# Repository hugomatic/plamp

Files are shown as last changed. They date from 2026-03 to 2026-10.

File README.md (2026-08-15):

# Plamp

Local-first hydroponics automation for Raspberry Pi and MicroPython Picos. Picos run lights and pumps independently; the Pi adds configuration, monitoring, pictures, agents, and a fallback web UI.

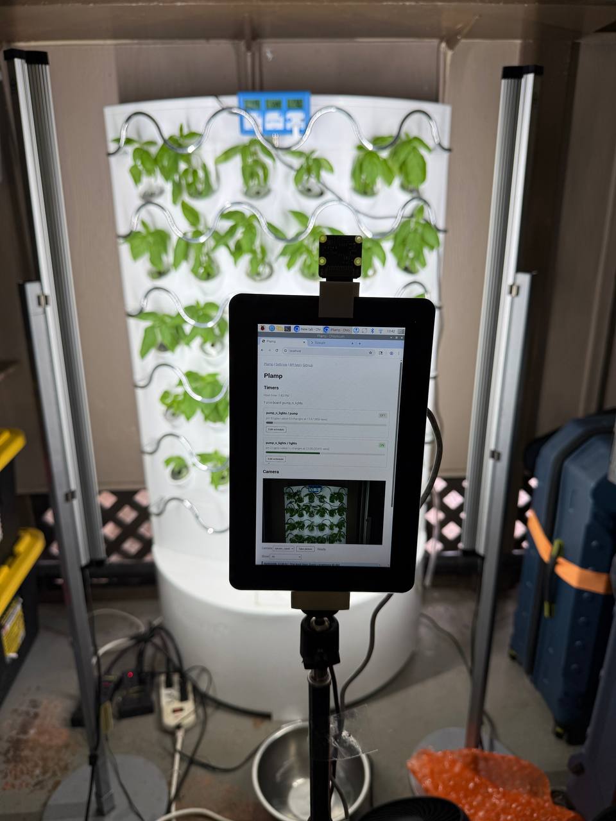
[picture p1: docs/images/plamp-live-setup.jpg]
Plamp running with basil tray, touchscreen UI, and camera


## Install

On a Raspberry Pi:

```bash
curl -fsSL https://raw.githubusercontent.com/hugomatic/plamp/main/deploy/bootstrap/install-plamp.sh | bash
```

This installs Plamp and starts `plamp-web` on `127.0.0.1:8000`. Useful options:

```bash
# Public port 80 through nginx
curl -fsSL https://raw.githubusercontent.com/hugomatic/plamp/main/deploy/bootstrap/install-plamp.sh | bash -s -- --public

# Update OS packages during installation
curl -fsSL https://raw.githubusercontent.com/hugomatic/plamp/main/deploy/bootstrap/install-plamp.sh | bash -s -- --update-os

# Install somewhere else
curl -fsSL https://raw.githubusercontent.com/hugomatic/plamp/main/deploy/bootstrap/install-plamp.sh | bash -s -- --plamp-dir ~/code/plamp
```

The installer labels required runtime dependencies separately from the tools
included for humans and agents. See [Host tools](./docs/host-tools.md).

Host lifecycle commands use `plampctl`:

```bash
systemctl is-active plamp-web
./plampctl restart
./plampctl upgrade
```

## Operate Plamp

Select this checkout, then use the `plamp` module's direct CLI:

```bash
source ./setup.sh
plamp context
plamp config get
plamp pico report pump_lights
plamp pico pulse pump_lights 21 5
plamp pico configure pump_lights compiled-state.json
plamp pico upgrade pump_lights compiled-state.json
plamp camera capture rpicam_cam0
```

Inspect the stable USB serial before onboarding a Plamp8 controller, and preview
the exact action before authorizing it:

```bash
plamp controllers candidates
plamp controllers add plamp8 --serial <serial> --profile plamp8
plamp controllers add plamp8 --serial <serial> --profile plamp8 --provision --apply
```

The middle command is a read-only preview: it reads the explicitly selected Pico
but changes neither firmware nor host files. Identityless, foreign, unsupported,
and PWM reports are rejected. Protocol 2 requires provisioning; protocol 3 can be
imported only when its generated revision and complete Plamp8 GPIO profile match
exactly. Add `--apply` without `--provision` to persist that observed validated
state. If the preview requires provisioning, the last command is the explicit
mutation that reflashes and resets the selected controller; confirm manual
switches and connected loads are safe first.

Use `-` instead of `compiled-state.json` to read the complete compiled scheduler state from stdin. Configure sends that state through the shared locked Pico protocol. Upgrade renders the current generic scheduler firmware, seeds both state slots, resets once, and verifies the reconnected report. These commands work while the service is running or stopped and do not contact `plamp-web`. Remote agents can use either the REST CLI or direct CLI over SSH.

During migration, the explicitly named REST compatibility client remains available as
`python3 -m plamp_cli`; it is not the command named `plamp`.

`setup.sh [DATA_DIR]` selects the checkout and instance for the current shell. It exports `PLAMP_ROOT` and `PLAMP_DATA_DIR`, and makes the checkout-owned `bin/plamp` launcher available without installing Plamp as a Python package. Without an argument, data defaults to `$PLAMP_ROOT/data`. Source another checkout's setup script to switch versions without leaving its executable paths behind.

See the direct CLI with `plamp --help`, or the
[REST compatibility reference](./plamp_cli/README.md).

## Generate printable CAD

The direct CLI generates the default product when one CAD system is available:

```bash
plamp cad generate
```

Discover the catalog or make a more specific selection when needed:

```bash
plamp cad systems
plamp cad models --system plamp
plamp cad sets plamp8 --system plamp
plamp cad products --system plamp
plamp cad generate --system plamp --product fuse-box
plamp cad runs plamp8
plamp cad show RUN_ID
```

Generate directly for normal work. `plan` is an optional advanced preview that
expands the same selection without invoking OpenSCAD. Generation can take
several minutes per job on a Raspberry Pi. Generated STL files, archived
source, manifests, and
OpenSCAD logs are instance data under `$PLAMP_DATA_DIR/cad/prints`, not source
files to commit. See [Host tools](./docs/host-tools.md#openscad-on-a-pi) for the
catalog, selection behavior, and archive layout.

## Web and API

Open `http://<raspberry-pi-ip>/` after a public install, or port `8000` otherwise.

- `/`: live controller state, schedule editing, and pictures
- `/settings`: hardware and configuration
- `/api/test`: executable API examples
- `/api/config`: desired configuration
- `/api/system`: host and detected hardware
- `/api/status`: resolved state and telemetry

The browser receives live updates through SSE. See [web service notes](./plamp_web/README.md).

## Configuration

Runtime configuration lives in `$PLAMP_DATA_DIR/config.json`; generated scheduler state lives beside it in `$PLAMP_DATA_DIR/timers/`. Both are local runtime data. The web system page shows the effective root and data paths.

Controllers contain desired device behavior, display settings, and a stable Pico USB serial. `/dev/ttyACM*` paths are rediscovered. See the [current contract](./docs/spec-current.md) for the normalized shape.

## Development

```bash
uv run python -m unittest discover -s tests -v
uv run uvicorn plamp_web.server:app --host 127.0.0.1 --port 8000 --reload
```

Stop the boot service before running a development server, then restore it afterward.

## Repository

- [`docs/spec-current.md`](./docs/spec-current.md): current contract and direction
- [`plamp/`](./plamp/): direct library and CLI
- [`plamp_cli/`](./plamp_cli/): REST-backed CLI
- [`plamp_web/`](./plamp_web/): REST, SSE, scheduled reports/pictures, and fallback UI
- [`pico_scheduler/`](./pico_scheduler/): generated MicroPython scheduler firmware
- [`things/`](./things/): printable parts

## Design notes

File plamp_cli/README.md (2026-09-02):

# Plamp CLI

Plamp currently has a primary direct CLI and an explicitly named REST compatibility
client.

## REST-backed CLI

`python3 -m plamp_cli` is the JSON-first compatibility client for `plamp-web` during
migration. The command named `plamp` does not point here.

```bash
cd /path/to/plamp
python3 -m plamp_cli --help
python3 -m plamp_cli config get
python3 -m plamp_cli controllers list
python3 -m plamp_cli pico-scheduler list
```

The default API is `http://127.0.0.1:8000`. Override it with `--base-url`, `--host`/`--port`, or `PLAMP_HOST`.

### Commands

```bash
# Desired configuration
python3 -m plamp_cli config get
python3 -m plamp_cli config set @config.json
python3 -m plamp_cli config controllers get
python3 -m plamp_cli config cameras get

# Discovery and current state
python3 -m plamp_cli controllers list
python3 -m plamp_cli controllers get pump_lights
python3 -m plamp_cli system status
python3 -m plamp_cli status --path controllers.pump_lights

# Scheduler operations
python3 -m plamp_cli pico-scheduler get pump_lights
python3 -m plamp_cli pico-scheduler set pump_lights @state.json
python3 -m plamp_cli pico-scheduler channels set-schedule pump_lights lights @schedule.json

# Pictures
python3 -m plamp_cli pics list --camera-id rpicam_cam0
python3 -m plamp_cli --pretty pics take --camera-id rpicam_cam0
python3 -m plamp_cli pics get <image_key> --out latest.jpg
python3 -m plamp_cli pics get <image_key> --stdout > latest.jpg
```

`status` streams `/api/status?stream=true`; repeated `--path` arguments select subtrees.

### Input and output

- Default stdout is compact JSON; use `--pretty` or `--table` where supported.
- Diagnostics go to stderr.
- JSON input accepts `@file.json` or `-` for stdin.
- `pics get --stdout` writes only image bytes.
- `pics get --out <path>` writes the file and no stdout payload.

Exit codes:

- `0`: success
- `2`: usage error
- `3`: API error
- `4`: network error
- `5`: local input error

### Remote use

Use HTTP directly:

```bash
python3 -m plamp_cli --host sprout.local system status
```

Or run the compatibility client explicitly through SSH:

```bash
ssh localhost 'cd /path/to/plamp && python3 -m plamp_cli config get'
ssh localhost 'cd /path/to/plamp && python3 -m plamp_cli pics get <image_key> --stdout' > latest.jpg
```

## Direct library CLI

The command named `plamp` calls the shared library without REST and shares the same
per-device filesystem locks as `plamp-web`:

```bash
source ./setup.sh
plamp pico report pump_lights
plamp pico pulse pump_lights 21 5
plamp pico configure pump_lights compiled-state.json
plamp pico upgrade pump_lights compiled-state.json
plamp camera capture rpicam_cam0
```

Inspect serials and preview a Plamp8 controller before authorizing changes:

```bash
plamp controllers candidates
plamp controllers add plamp8 --serial <serial> --profile plamp8
plamp controllers add plamp8 --serial <serial> --profile plamp8 --provision --apply
```

`controllers candidates` only enumerates attached Raspberry Pi USB serial/device
pairs; inspect the output and select the intended serial explicitly. The middle
command reads that Pico's complete report and emits a read-only JSON preview. It
does not change firmware or host files. Identityless, foreign, and unsupported
protocol reports are rejected. Protocol 2 always previews as `provision`.
Protocol 3 previews as `import` only when its generated revision and complete
IDs, pins, GPIO types, and enabled flags exactly match the Plamp8 profile. Use
the same command with `--apply` and no `--provision` to persist that validated
observed state without changing firmware. When the action is `provision`, the
last command authorizes a reflash and reset of the selected
Pico before import. It writes the pre-provision report to
`$PLAMP_DATA_DIR/controller-backups/<controller>-<serial>-pre-provision.json`;
verify switches and connected loads are safe first. `--provision` without
`--apply` is rejected.

Commands emit JSON on stdout and diagnostics on stderr. `PLAMP_ROOT` and
`PLAMP_DATA_DIR` select local paths; `--lock-dir` and `--timeout` control hardware
locking and operation budgets. Direct hardware commands may run while the service is
active because access is serialized through shared locks.

Complete scheduler states and protocol 3 reports require `enabled` on every base
device. Only `gpio` is supported; PWM state, reports, and configuration fail
validation and are never converted. The Pico enforces disabled base schedules by
holding GPIO output at zero, freezing schedule phase, and preserving the disabled
state across reboot. Timed ON/OFF overrides remain available on disabled channels;
on expiry they return to OFF. Complete reports include disabled devices and report
their effective output value.

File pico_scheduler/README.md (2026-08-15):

# Pico Scheduler

`pico_scheduler` generates one generic MicroPython `main.py` for Raspberry Pi
Picos that run Plamp schedules. For a given firmware source revision and build
options, every controller receives the same application.

## Generation

The generator accepts a firmware revision and one build-time option:

```python
GeneratorOptions(loop_sleep_ms=20)
```

All inputs that can change the rendered application live under `src/`. The
firmware revision is the latest Git commit touching that directory; README and
example changes at the package root do not change firmware identity.

Automatic rendering uses these defaults. Controller IDs, pins, device lists,
and schedules are not generator inputs. The embedded revision identifies the
firmware sources that produced the application.

`plamp firmware generate` can render the generic source for inspection. The
normal upgrade path is `python -m plamp pico upgrade`, which also seeds both
persistent state slots and verifies the report after reset.

## Firmware contract

Generated firmware:

- runs GPIO schedules without the host and rejects every non-`gpio` output type;
- stays silent during routine schedule transitions;
- answers `r` with one newline-delimited JSON report;
- accepts one complete JSON `configure` document, persists it in alternating
  generation-numbered state files, applies it, and returns a matching report;
- answers `p <pin> <seconds>` with a report or error;
- rejects a pulse when the GPIO is already on;
- applies a pulse as a temporary overlay, then restores the scheduler's value.

The host requests a report before a schedule transaction. If the reported
firmware identity is missing or outdated, it seeds the committed state, copies
the generated application with `mpremote`, resets once, rediscovers USB, and
requires a valid matching report. Otherwise it sends the proposed state without
flashing or resetting the Pico.

The Pico reloads its newest valid persisted state after power loss. It resumes
the stored phase but cannot reconstruct time spent without power, so the host
must not claim wall-clock alignment without later clock reconciliation. See
[the current contract](../docs/spec-current.md).

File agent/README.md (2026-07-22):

# Plamp agent entrypoint

Start with the [Plamp workflow skill](skills/plamp-workflow/SKILL.md). It
explains checkout setup and routes host lifecycle, direct device/API, and CAD
work to the correct command.

For OpenSCAD models, printable artifacts, or new parts under `things/`, also
read the [OpenSCAD CAD skill](skills/openscad-cad/SKILL.md) and its linked
repository conventions.

From a clone, source `./setup.sh` to select that checkout and its data directory.
If shell setup is undesirable, invoke the checkout launcher as `bin/plamp`.

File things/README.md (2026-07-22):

# things

## CAD workflow

Run CAD commands from the repository root after `source ./setup.sh`, or invoke
the checkout launcher as `bin/plamp`:

```bash
plamp cad new PART --template cad
plamp cad validate PART
plamp cad plan PART
plamp cad generate PART
```

`openscad` must be available on `PATH` for generation. Discovery, validation,
and planning remain useful without it.

## Checklist

See the repo-level [`CHECKLIST.md`](../CHECKLIST.md) for the general checklist and example manual checks.

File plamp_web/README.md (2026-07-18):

# Plamp Web Service

`plamp-web` provides REST, SSE, Pico monitoring, scheduled camera capture, and the fallback website. Agents and other web apps use the same API.

## Run

```bash
uv run uvicorn plamp_web.server:app --host 127.0.0.1 --port 8000
```

Production installation and service control belong to `plampctl`. With nginx enabled, requests follow `browser or agent -> nginx :80 -> plamp-web :8000`.

Useful pages:

- `/` - static main Pico scheduler and camera client; it loads all runtime state through REST and SSE
- `/settings` — static hardware and configuration client; it loads and saves through REST
- `/controllers/{controller}` — static controller diagnostics and command client using REST and SSE
- `/system` — static host diagnostics and service-action client; logs load on demand through REST
- `/api/test` — runnable API examples
- `/openapi.json` — machine-readable API

## Controller contract

- The Pico is silent until commanded.
- The host requests a report every five seconds. Linux USB events provide immediate add/remove evidence.
- A controller is `OK` only after a valid report. Otherwise it is `ERROR` with the failed step, serial, port, timestamps, and received raw lines.
- Successful periodic reports update SSE and the in-memory serial log without writing an INFO line every five seconds.
- Serial connections are short transactions protected by shared locks; the service does not permanently own the port.

Schedule changes are one controller-wide transaction:

1. Read and validate a proposed controller.
2. Obtain a fresh report from the configured Pico.
3. Compile every configured channel and stage config plus applied state.
4. Flash once and wait for the Pico's valid post-flash report.
5. Commit both local files.

Any failure before step 5 returns an error and leaves desired config and applied state unchanged. There is no offline queue or automatic reconnect apply.

## Pico Scheduler State

Desired configuration is `data/config.json`. Semantic schedules live under `controllers.<id>.settings.devices`; generated state files keep device state in `data/timers/<controller-id>.json`.

The main API groups are:

- `/api/config` — desired configuration
- `/api/status` — combined state and SSE
- `/api/controllers` — controller health, schedule, report, pulse, and low-level apply operations
- `/api/camera` — captures and images
- `/api/system` — host facts and detected hardware

Application diagnostics are stored in `data/plamp.log` and exposed by `/api/logs` and the controller serial-log endpoint.

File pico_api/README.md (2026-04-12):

# pico_api

Minimal FastAPI host app for the Pico scheduler.

This is host-only code. The MicroPython firmware stays in `../pico_scheduler/`, and the API reads host runtime information while leaving the Pico serial port alone.

## Setup

Install `uv` on the Raspberry Pi if it is not already available. The standalone Linux installer from Astral is:

```bash
curl -LsSf https://astral.sh/uv/install.sh | sh
```

After installation, restart the shell or reload your shell profile so the new `uv` binary is on `PATH`, then check it:

```bash
command -v uv
uv --version
```

From the repo root, `uv run` will install the Python requirements from `pyproject.toml` into uv's managed environment.

```bash
cd /home/hugo/.openclaw/workspace/code/plamp
uv run python -c "import fastapi, serial, uvicorn"
```

## Timer API

Timer roles are configured in `../data/config.json`. The app creates `../data/`, `../data/timers/`, and an empty config file if they do not exist. The `data/` directory is local runtime data and is ignored by git. Each role maps to a Pico serial number:

```json
{
  "timers": [
    {
      "role": "pump_lights",
      "pico_serial": "e66038b71387a039"
    }
  ]
}
```

Each timer role has a scheduler state file under `../data/timers/`. For example, `../data/timers/pump_lights.json` is the state file for the `pump_lights` Pico role. Event IDs such as `pump` and `lights` identify the timer on that board, while `ch` identifies the GPIO pin on that board.

Read the timer state:

```bash
curl http://localhost:8000/api/timers/pump_lights
```

Stream timer state changes for that role:

```bash
curl -N 'http://localhost:8000/api/timers/pump_lights?stream=true'
```

Each timer role gets one background monitor thread at server startup. The monitor owns the Pico serial connection, keeps the timer state current from Pico reports, emits stream events to connected HTTP clients, and temporarily closes serial before copying state and resetting the Pico. Reported timer state uses `elapsed_t` for total elapsed seconds, `cycle_t` for the current pattern-cycle offset, and `current_value` for the output value.

Write a new timer state. PUT always saves the host state file, copies it to the Pico, and resets the timer:

```bash
curl -X PUT http://localhost:8000/api/timers/pump_lights \
  -H 'content-type: application/json' \
  --data @data/timers/pump_lights.json
```

A successful PUT returns a short success message. If the Pico is disconnected or `mpremote` fails, the response explains which step failed and the monitor keeps retrying the serial connection by Pico serial.

The browser test page is available at:

```text
http://localhost:8000/timers/test
```

It has separate GET and PUT sections, separate role inputs for each section, an editable JSON payload, generator groups for a quick 5-second on/off pin test and a pump/lights example, and generated curl commands for both GET and PUT.

GET and PUT each show their own confirmation prompt, HTTP status, and response body so the page can be used before building a real UI. PUT always copies state to the Pico and resets it.

## Run The Settings Page

During development, run with reload on port 8000:

```bash
cd /home/hugo/.openclaw/workspace/code/plamp
uv run uvicorn pico_api.server:app --host 0.0.0.0 --port 8000 --reload
```

For deployment, use port 80 through a service or reverse proxy instead of the development reload server.

Open the main timer page:

```text
http://<hostname>:8000/
```

Or use the Pi IP address directly:

```text
http://<raspberry-pi-ip>:8000/
```

The settings JSON version is available at:

```bash
curl http://localhost:8000/settings.json
```

The app log is written under local runtime data and rotated when it reaches 1 MB:

```text
data/plamp.log
data/plamp.log.1
```

Read recent log lines through the API:

```bash
curl 'http://localhost:8000/api/logs?lines=200'
```

The page reports detected Pico boards, network devices, monitor state, log path, and host software paths. The JSON keeps a default-route field because it is useful when debugging which network interface and gateway the Pi is actually using, but the page keeps that detail out of the main view.

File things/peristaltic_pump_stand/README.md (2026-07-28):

# Peristaltic pump stand

This is a small U-stand for one or more peristaltic pumps. The horizontal
plate has a 29 mm motor opening and an M3 mounting pair on the same centre
line, initially measured at 48.5 mm apart. Two end panels lift the plate 55 mm
above the table; their tabs locate into slots in the plate.

Generate the printable pieces separately:

```bash
plamp cad generate peristaltic_pump_stand --set plate
plamp cad generate peristaltic_pump_stand --set legs
```

The default is two pump stations at 62 mm centre-to-centre. Change the count
or `pump_spacing` from the command line when the pump layout changes:

```bash
plamp cad generate peristaltic_pump_stand --set plate \
  --define 'pump_count=2' --define 'pump_spacing=62'
```

The 29 mm motor opening and 48.5 mm M3 spacing are initial measurements.
Print a short plate fit check before committing to a long production plate.
The two 5.5 mm M5 table-mounting holes sit in round ears, centred on the
plate centreline just outside the end-panel legs.

For a visual check only:

```bash
plamp cad generate peristaltic_pump_stand --set assembly
```

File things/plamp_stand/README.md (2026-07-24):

# plamp_stand

Simple printed stand / camera mount parts for the plamp setup.

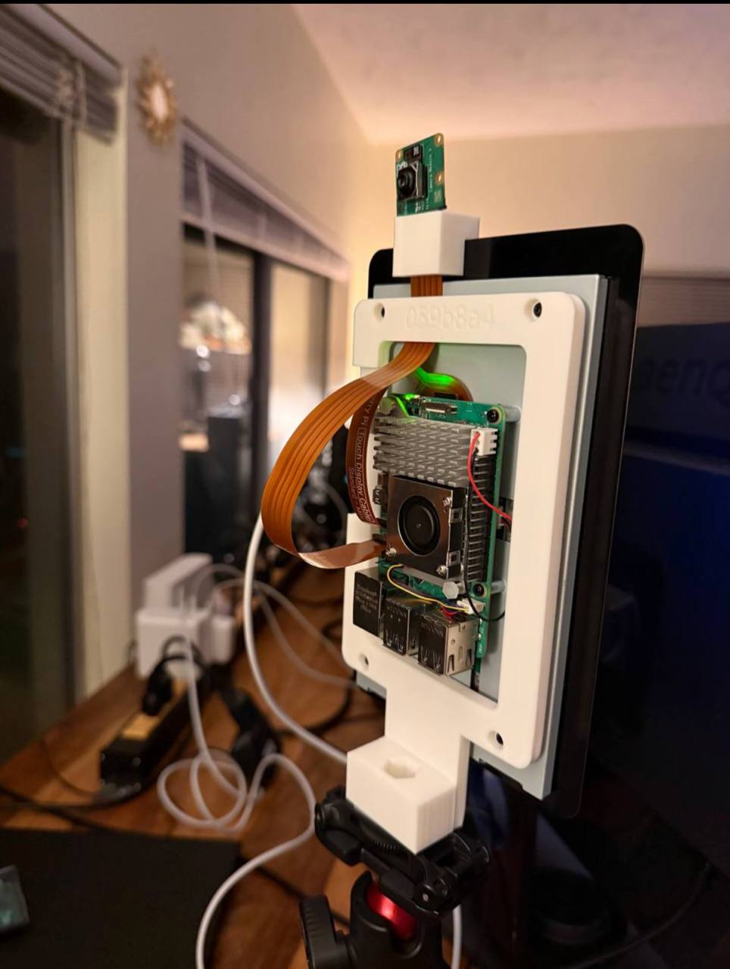
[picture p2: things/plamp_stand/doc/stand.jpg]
plamp stand reference


## Files

- `plamp_stand.scad` - OpenSCAD source
- `check_generates_stl_files_from_scad.bash` - manual smoke test

## Generate

From the repository root after `source ./setup.sh`:

```bash
plamp cad validate plamp_stand
plamp cad plan --system plamp plamp_stand --all-sets
plamp cad generate --system plamp plamp_stand --all-sets
```

If you are changing the model or generation flow, run the manual check from the repo checklist:

```bash
cd /path/to/plamp/things/plamp_stand
bash ./check_generates_stl_files_from_scad.bash
```

## Reference image

A local reference image may exist at:

- `./doc/stand.jpg`

If that file is missing in GitHub or another checkout, treat it as optional documentation, not as part of the generation contract.
The source of truth is the SCAD file and its adjacent model sidecar.

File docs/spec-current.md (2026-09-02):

# Plamp: Current Contract

Plamp is local-first hydroponics automation designed for humans and agents. Core schedules must continue with only Pico power. A Raspberry Pi adds monitoring, pictures, configuration, and remote access; Internet access is optional.

## Current System

- `plamp_web`: one FastAPI service providing REST, SSE, scheduled camera captures, Pico monitoring, and the fallback website.
- `plamp_cli`: explicitly named JSON-first REST compatibility client.
- `plamp`: shared hardware/domain library and the primary direct CLI used by the REST service and local operations.
- `pico_scheduler`: one generic, persistent, runtime-configurable MicroPython application.
- `data/`: desired configuration, generated controller state, logs, pictures, and other runtime data.

The web collector and direct CLI share per-device filesystem locks. Each transaction discovers the current tty, opens it, exchanges a complete message, and closes it.

## Configuration and State

`data/config.json` is the desired host configuration. Top-level groups are `controllers` and `cameras`.

Scheduler controllers normalize to:

```json
{
  "type": "pico_scheduler",
  "payload": {
    "pico_serial": "e66038b71387a039",
    "report_every": 10,
    "devices": []
  },
  "settings": {
    "devices": {
      "pump": {
        "pin": 15,
        "output_type": "gpio",
        "programming": "enabled",
        "visibility": "visible",
        "editor": {"kind": "cycle"}
      }
    }
  }
}
```

Controller IDs are unique. Device IDs are unique within a controller. Pins may not collide within a controller. The stable Pico USB serial identifies hardware; tty paths do not.

Observed reports describe runtime state. They do not replace desired configuration or host-only preferences.

Protocol 3 complete scheduler states require an `enabled` boolean for every base
device. Complete Pico reports include that field along with the device identity,
type, pin, schedule, phase, and current output value; partial telemetry fragments
are not a substitute for a complete report. Host configuration exposes the same
choice as semantic `programming: "enabled"` or `programming: "disabled"`.

## Interfaces

Agents should receive machine-readable JSON on stdout and diagnostics on stderr.

The primary `plamp` command calls the shared module directly and does not require the
REST service. Its hardware path includes:

```bash
plamp pico report <controller>
plamp pico pulse <controller> <pin> <seconds>
plamp pico configure <controller> <compiled-state.json>
plamp pico upgrade <controller> <compiled-state.json>
```

Inspect attached Pico serials and preview Plamp8 onboarding before authorizing any
mutation:

```bash
plamp controllers candidates
plamp controllers add plamp8 --serial <serial> --profile plamp8
plamp controllers add plamp8 --serial <serial> --profile plamp8 --provision --apply
```

`controllers candidates` enumerates Raspberry Pi USB serial/device pairs without
opening a candidate. Inspect the returned serials and pass the intended hardware
serial explicitly. The middle command obtains one complete report from only that
serial and returns a read-only JSON preview; it changes neither Pico firmware nor
host files. Reports without firmware identity, foreign firmware families, and
protocols other than scheduler protocol 2 or 3 are rejected. Protocol 2 always
requires provisioning. Protocol 3 is importable only when its revision is the
current generated scheduler revision and every ID, GPIO pin, type, enabled flag,
and required state field exactly matches the Plamp8 profile; other valid profile
states require provisioning. If the preview action is `import`, register that
validated observed state with `--apply` but without `--provision`. If the action
is `provision`, the last command is the explicit destructive authorization: it
saves the pre-provision report under
`$PLAMP_DATA_DIR/controller-backups/<controller>-<serial>-pre-provision.json`,
reflashes and resets the selected Pico, verifies the resulting protocol 3 report,
and then imports it. Confirm manual switches and connected loads are safe before
running it. `--provision` without `--apply` is rejected.

`python3 -m plamp_cli` remains an explicitly named REST compatibility client during
migration. It does not own the `plamp` command.

Primary HTTP surfaces:

- `/api/config`: persisted desired configuration
- `/api/system`: host facts and detected hardware
- `/api/status`: resolved state and telemetry, including SSE
- `/api/controllers`: controller reads and commands
- `/api/camera`: capture and image access

The web pages are replaceable REST/SSE clients, not the source of domain behavior.

## Firmware

The scheduler generator renders one generic `main.py` for a firmware source
revision. Controller identity, pins, devices, and schedules are not compiled
into it. Its only build-time option is `loop_sleep_ms` (default `20`);
automatic rendering uses that default.

Schedule changes send and verify one complete persistent runtime state. A
legacy or outdated Pico is upgraded once during the next mutating schedule
transaction, using the committed state before applying the proposal. Read-only
reports never upgrade firmware, and ordinary schedule changes do not reset USB.

Scheduler protocol 3 persists and reports each base device's required `enabled`
state. Scheduler state and controller configuration accept only `gpio`; a PWM
state, report, or configuration is rejected and is never converted or migrated.
The Pico itself enforces disabled GPIO base schedules by driving them to zero,
freezing their schedule phase, and preserving the disabled state after reboot.
A bounded timed overlay may force either ON or OFF independently of that saved
schedule. Disabling a channel does not cancel an active overlay; when the overlay
expires, the output returns to the current base schedule, or OFF when that schedule
is disabled. Disabled base devices remain present in complete reports with
`enabled: false`; `current_value` reports the effective physical output, including
any active overlay.

`pico_scheduler` is the only implemented firmware family. Dosing pumps attached
to Plamp8 use bounded GPIO ON/OFF overrides requested by a human, host algorithm,
or agent; the Pico ends each override locally and restores the configured base
state.
A future pH, EC, or PPM measurement MCU requires a separate hardware-backed
protocol design rather than a placeholder family.

## Direction

The approved target is agent-first:

- one shared `plamp` library under the CLI and REST service;
- short cross-process-locked Pico and camera transactions;
- CLI usable locally or through SSH without the service;
- demand-driven full Pico reports with host-controlled polling;
- first-class MicroPython provisioning and application recovery;
- daily clock-drift detection and explicit reconciliation policy;
- a hardware-backed contract for any future measurement MCU;
- optional web apps using REST and SSE.

See [Agent-First Plamp Architecture](./superpowers/specs/2026-07-14-agent-first-plamp-architecture-design.md).

## Reliability Rules

- Do not require cloud access for schedules or recovery.
- Keep desired configuration separate from observed state.
- Do not store tty paths as hardware identity.
- Serialize access to each Pico and camera across processes.
- Prove firmware readiness with a valid protocol response, not a successful port open.
- Label planned behavior as direction until it ships.

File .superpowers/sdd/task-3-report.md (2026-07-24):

# Task 3 Report: CAD system render planning

## Status

Implemented direct set and nested product expansion into immutable render plans,
including stable fingerprints, artifact identifiers, product memberships, effective
variable provenance, raw defines, JSON serialization, and the prerequisite repeated
sibling validation correction.

## TDD evidence

### RED

Command:

```text
.venv/bin/python -m unittest tests.test_cad_system tests.test_cad_planning -v
```

Observed 18 tests run with two expected errors:

- `ModuleNotFoundError: No module named 'plamp.cad_planning'`
- identical sibling assignments failed with `CAD125 ... require distinct variants`

### GREEN

Command:

```text
.venv/bin/python -m unittest tests.test_cad_model tests.test_cad_system tests.test_cad_planning tests.test_cad_generation -v
python3 -m py_compile plamp/cad_planning.py plamp/cad_values.py
git diff --check
```

Result: 77 tests passed; compilation and diff checks exited successfully.

### Full suite

Command:

```text
.venv/bin/python -m unittest discover -s tests -v
```

Result: 678 tests passed in 19.160 seconds.

## Files

- Created `plamp/cad_planning.py`
- Created `plamp/cad_values.py`
- Created `tests/test_cad_planning.py`
- Modified `plamp/cad_generation.py`
- Modified `plamp/cad_recipes.py` to retain the legacy API while sharing value handling
- Modified `plamp/cad_system.py`
- Modified `tests/test_cad_system.py`

## Commit

`Plan nested CAD products` (the Task 3 commit at `HEAD`)

## Self-review

- Confirmed depth-first declared order and deepest-product-outward precedence.
- Confirmed CLI typed/set/raw precedence and provenance.
- Confirmed fingerprints cover schema, manifest, source, model, set, typed variables,
  and raw expressions and use canonical JSON plus SHA-256.
- Confirmed fingerprint deduplication retains unique product paths.
- Confirmed direct named sets preserve requested order and `all_sets` preserves model order.
- Confirmed legacy recipe imports remain usable until Task 8.
- Confirmed repeated sibling descriptions do not count as effective assignments, while
  variable/profile/slicing differences still require distinct variants.

## Concerns

None.

## Review fix: manufacturing metadata identity

Review found that effective product/item profiles and slicing were discarded,
allowing profile-only or slicing-only sibling variants to collapse during
fingerprint deduplication.

### RED

```text
.venv/bin/python -m unittest \
  tests.test_cad_planning.CadPlanningTests.test_profile_only_sibling_variants_remain_distinct_and_compose_root_to_leaf \
  tests.test_cad_planning.CadPlanningTests.test_slicing_only_sibling_variants_remain_distinct_and_overlay_deepest_outward -v
```

Result: both tests failed because each plan contained one job instead of two.

### GREEN

```text
.venv/bin/python -m unittest tests.test_cad_planning -v
```

Result: 9 tests passed. Effective profiles and slicing now survive in immutable
jobs and JSON, and both participate in the canonical fingerprint.

### Fix commit

`Preserve CAD manufacturing plan metadata` (the review-fix commit following the
Task 3 implementation commit)

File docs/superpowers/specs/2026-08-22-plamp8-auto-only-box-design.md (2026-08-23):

# Plamp8 Auto-Only Enclosure Design

## Goal

Add an auto-only Plamp8 enclosure variant for the future dosing box while preserving the existing toggle-equipped enclosure. Construction style and control style remain independent choices:

- separate floor and walls, with toggles;
- fused box, with toggles;
- separate floor and short walls, auto-only;
- fused short box, auto-only.

This change covers enclosure geometry only. Pump selection, pH electronics, wiring, and control software are separate work.

## Product Contract

Keep the existing product names and behavior unchanged:

- `split-box`: separate floor and walls, 128 mm high, with toggles;
- `fuse-box`: fused floor and walls, 128 mm high, with toggles.

Add two products:

- `split-box-auto`: separate floor and walls, 75 mm high, without toggles;
- `fuse-box-auto`: fused floor and walls, 75 mm high, without toggles.

The CAD model should expose a single control-style parameter, such as `auto_only`, alongside the existing choice between split and fused construction. Product definitions set this parameter; they should not require duplicate auto-only part modules.

Auxiliary products and individual views remain available. Their default behavior stays toggle-equipped unless a caller explicitly sets the auto-only parameter.

## Auto-Only Geometry

When auto-only mode is enabled:

- set enclosure wall height to 75 mm;
- remove all eight top-panel toggle holes;
- remove the matching switch-body pockets and keepouts from the sub-panel;
- remove the `Auto`, `Off`, and `On` state labels;
- retain the existing connector label font sizes;
- center each channel label over its remaining connector;
- center each of the four AC outlet openings within its former outlet-and-toggle channel area;
- center each of the four XT60 openings within its former connector-and-toggle channel area;
- keep connector mounting holes, retention geometry, and channel ordering unchanged.

The sub-panel USB support rib must be relieved directly above each AC
socket, matching the existing lower socket-rim relief. Each upper relief
follows the selected AC connector center, removes the rib across the socket
envelope, and leaves the rib intact between and around sockets. This applies
to both control styles so socket removal and wiring access do not depend on
whether toggles are fitted.

Centering is derived from each existing channel region, not from the whole panel. This preserves equal channel spacing and makes the AC and DC layouts visually consistent.

When auto-only mode is disabled, the current 128 mm enclosure, connector
locations, toggles, pockets, and labels remain unchanged. The new upper
AC-socket relief is the sole geometry change shared with manual mode.

## Height And Clearance

The Pico-Relay-B mounts directly on the 3 mm floor and has an observed height of 18 mm. The AC socket harness requires approximately 48 mm downward from the panel top to accommodate the fork connector and its 90-degree wire bend.

At a 75 mm wall height, the nominal vertical separation is:

```text
75 - 3 - 18 - 48 = 6 mm
```

The assembly model should represent these measured envelopes and assert that they do not overlap. The 6 mm is a nominal packaging margin, not permission to force the harness against the relay board. Final acceptance requires an assembly inspection and a physical dry fit because the wire bend changes when pressure is applied.

The shorter height applies only to auto-only mode. It must work identically with separately printed walls and the fused box.

## XT60 Flyback Diodes

Each 12 V inductive output will use a 1N5408 flyback diode across the XT60 terminals. The diode is part of the removable connector-and-wire assembly:

- solder it directly across the XT60 terminals with correct reverse-bias polarity;
- insulate exposed conductors with heat-shrink;
- keep it tucked within the connector's wiring-side clearance envelope;
- ensure the complete XT60, diode, and lead assembly can pass through both the top-panel and sub-panel XT60 openings during disassembly.

Do not add diode lead holes, fixed clips, or pockets to the enclosure. A separate disconnect would add contacts and allow the protection diode to be accidentally omitted. The existing removable XT60 assembly already supplies the useful disconnect boundary.

CAD verification should include a conservative wiring-side envelope behind every XT60. Polarity belongs in the wiring documentation or wiring-side marking, not in geometry that traps the diode.

## Implementation Shape

The primary changes belong in:

- `things/plamp8/plamp8.scad`: add the control-style parameter, derive height and channel placement, conditionally remove toggle geometry and labels, and add clearance envelopes/assertions;
- `cad/plamp.system.cad.json`: add the two auto-only enclosure products and pass the mode parameter to every affected item;
- CAD tests or metadata tests: verify product expansion and effective variables for all four enclosure products.

Shared placement functions should return connector and label centers for a channel. Existing manual coordinates remain the non-auto branch so the established enclosure does not shift accidentally.

## Verification

Before rendering:

- validate the Plamp8 model and CAD system metadata;
- plan all four enclosure products and confirm their exact jobs and effective variables;
- verify the manual products retain 128 mm height and toggle geometry;
- verify the auto-only products use 75 mm height and no toggle geometry.

Render both auto-only products through the managed CAD workflow. Inspect the complete logs and confirm every STL is present and non-empty. Visually inspect top panel, sub-panel, and assembly views for:

- centered AC connectors and labels;
- centered XT60 connectors and labels;
- absence of toggle holes, switch pockets, and state labels;
- unchanged connector retention and fastener access;
- lower socket-rim and upper USB-support-rib relief aligned to every AC socket;
- relay, AC harness, and XT60 wiring-envelope clearance;
- top-panel removal and XT60 assembly removal without trapped wiring.

Render or plan the existing manual products as regression coverage. Complete the design with a physical dry fit of an AC socket harness, Pico-Relay-B, and one XT60 connector carrying an insulated 1N5408 before committing to the full print.

## Non-Goals

- No pH probe, ADC board, temperature probe, pump mount, reservoir, or tubing geometry.
- No dosing or pH-control software.
- No relay-channel reassignment.
- No direction reversal; the selected peristaltic pumps are operated in one direction.
- No diode socket or separate diode disconnect.
- No reduction of the toggle-equipped enclosure height.

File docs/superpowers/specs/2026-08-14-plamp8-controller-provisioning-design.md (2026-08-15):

# Plamp8 Controller Provisioning and Import

## Goal

A Plamp8 controller should arrive with channel identities that match the writing
on its box, enforce disabled outputs locally, and install on a Plamp host without
creating a surprising empty controller. Communication with an unassigned USB
Pico begins only after the user explicitly asks to add it.

The first implementation remains deliberately small: complete reports, one
Plamp8 hardware profile, explicit provisioning, and explicit import. Delta
reports, checksums, automatic discovery conversations, and general controller
profile management are out of scope.

## User-facing principles

- USB enumeration may identify a possible Pico by operating-system metadata, but
  Plamp must not open it, request a report, reflash it, or send commands merely
  because it was plugged in.
- The user initiates communication with **Add/import controller**.
- Import observes and records controller state. It never changes outputs,
  schedules, firmware, or controller storage.
- Provisioning is a separate, visibly mutating operation. The UI must call it
  **Upgrade, provision, and import** and preview its effects before confirmation.
- Host desired configuration and Pico observed state remain distinct. Plamp
  commits imported host configuration only after receiving and validating a
  complete report.
- Device IDs are their only names. There is no separate device label.

## Web UX conventions

The workflow uses progressive disclosure and conventional action naming:

- The configuration page replaces **Pico schedulers** with the exact heading
  **Plamp Pico relay controllers**. Firmware diagnostics may still expose the
  technical family name `pico_scheduler`.
- An unassigned candidate appears as a compact row containing its stable USB
  serial and operating-system description. Its primary action is
  **Add/import controller**.
- Inspection is read-only. While it runs, the selected row shows bounded
  progress and remains associated with the same serial; the rest of Settings
  remains usable.
- A compatible provisioned controller receives an **Import** confirmation that
  previews only the host configuration to be created.
- A controller requiring mutation receives a distinct **Upgrade, provision,
  and import** confirmation. The confirmation shows the before/after channel
  table, firmware change, restart warning, preserved schedules, and channels
  that will be forced off.
- Primary actions use verbs that describe their effects. Generic **Save** does
  not stand in for inspection, import, upgrade, or provisioning.
- Success returns the user to the existing controller page with configured and
  live state visible. Failure leaves the preview and evidence available for
  retry or diagnosis; it does not redirect to an apparently empty controller.
- Technical firmware identity and raw report details are available in an
  expandable diagnostics section without dominating the normal path.
- Buttons, confirmations, progress, errors, focus handling, and tables remain
  keyboard accessible and do not rely on color alone.

Confirmation obtains one fresh report from the selected USB serial. If it no
longer matches the preview, the operation stops and shows the updated preview.

## Canonical Plamp8 profile

The profile is keyed by GPIO pin because provisioning replaces prototype IDs
while preserving the program already associated with each physical output.

| GPIO pin | Device ID | Initial enabled state |
| ---: | --- | --- |
| 21 | `ph_up` | disabled |
| 20 | `ph_down` | disabled |
| 19 | `agitator` | disabled |
| 18 | `nutrients` | disabled |
| 17 | `pump` | enabled |
| 16 | `fan` | enabled |
| 15 | `lights_1` | enabled |
| 14 | `lights_2` | enabled |

The same exact mapping is the contract for controller provisioning and Plamp8
box lettering. The current CAD names `Lights` and `Aux` are stale and must be
corrected directly to `Lights 1` and `Lights 2`.

## Device IDs and display names

New device IDs use lowercase snake case. User-facing pages derive a display name
by replacing underscores with spaces and uppercasing the first character:

- `pump` becomes `Pump`;
- `ph_up` becomes `Ph up`;
- `lights_1` becomes `Lights 1`.

Settings and diagnostics continue to expose the exact raw ID. Controller and
camera labels are unaffected; this design removes only scheduled-device labels.
An existing device-label key is ignored and omitted the next time that
configuration is successfully written; it never renames the device ID. This
does not require a standalone migration framework.

## Firmware state and disabled outputs

The scheduler protocol gains a required Boolean `enabled` field on every device.
This is a protocol compatibility change and therefore advances the firmware
protocol version. Complete reports include `enabled` alongside the existing ID,
type, pin, timing, pattern, and current value.

The scheduler supports only `gpio` outputs. Host state, persisted configuration,
Pico configuration, reports, and UI input reject PWM explicitly; no compatibility
path converts or migrates it.

For an enabled device, existing scheduler and pulse behavior remains unchanged.
For a disabled device, the Pico itself must:

1. drive the logical output to `0` when the disabled state is applied;
2. restore logical `0` on boot before ordinary scheduling begins;
3. exclude the device from schedule advancement and output transitions;
4. retain its stored pattern and phase without executing them;
5. continue including it in complete reports with `enabled: false` and
   `current_value: 0`; and
6. reject pulse or other commands that could energize it with a structured
   disabled-device error.

There is no configurable safe value in this slice. Logical `0` is the Plamp8
safe-off value. Enabling a channel is an explicit configuration transaction;
the proposal supplies the schedule and phase that will become active.

The Pico validates the complete proposed state before persistence or output
changes. Configure verification compares `enabled` in addition to the existing
static fields.

## Explicit add and compatibility check

An unassigned candidate initially exposes only non-invasive operating-system
facts such as USB serial, vendor, model, and tty candidate. Clicking
**Add/import controller** authorizes a bounded serial transaction:

1. open only the selected serial device;
2. request one fresh complete report;
3. validate firmware family, revision, protocol, and report structure;
4. compare the reported device mapping with the selected Plamp8 profile; and
5. present the next applicable action.

The host does not create or save a controller merely because the serial port
opened. A missing, malformed, or incompatible report produces a specific error
and leaves host configuration unchanged.

If the controller already runs the expected firmware and reports the complete
profile, the offered action is **Import**. If it runs the immediately preceding
known scheduler protocol or does not match the Plamp8 profile, the offered
action is **Upgrade, provision, and import**. Arbitrary unidentified firmware is
rejected rather than handled by a general compatibility framework.

## Upgrade, provision, and import transaction

The current installed Plamp8 reports current protocol 2 firmware and prototype
IDs `one` through `eight`. Once the enabled-state protocol ships, the explicit
provisioning transaction performs this controlled transition:

1. Acquire the selected Pico lock and obtain a fresh, valid protocol 2 report.
2. Save the complete pre-change report as recovery evidence.
3. Join each reported device to the Plamp8 profile by GPIO pin.
4. Preserve type, pattern, and captured phase for every matched pin.
5. Replace the prototype ID with the profile ID.
6. Set GPIO 21, 20, 19, and 18 disabled; provisioning will intentionally drive
   those four outputs off.
7. Set GPIO 17, 16, 15, and 14 enabled and preserve their schedules and captured
   phases.
8. Render and install the expected generic scheduler firmware and its complete
   provisioned state, then reset and rediscover the selected USB serial.
9. Require a fresh complete report with the expected firmware identity, exact
   profile IDs and pins, expected enabled states, and preserved patterns.
10. Only after verification, import the reported controller and devices into
    host configuration.

The confirmation explains that the firmware upgrade restarts the Pico and may
briefly drive outputs safe-off. It lists the four channels that will remain
disabled. It does not claim that a firmware restart can preserve electrical
output continuously.

If validation fails before mutation, nothing changes. If flashing,
rediscovery, configuration, or verification fails after mutation, Plamp does
not commit the host import or claim success. It retains the captured report,
raw serial evidence, and failed stage for explicit recovery. It does not
silently retry a mutating operation.

## Read-only import

Import consumes a fresh, compatible complete report and creates or fills the
host controller bound to that Pico serial. For the existing empty `plamp8`
controller, it fills that controller rather than creating a duplicate.

Import records:

- controller firmware identity and Pico USB serial;
- device ID, pin, output type, and enabled state;
- exact pattern and captured runtime phase; and
- report interval when available.

A two-step on/off pattern may be represented as a cycle editor only when that
conversion is lossless. Plamp must not infer that a reported pattern originated
as a host-clock daily window. Patterns that cannot be losslessly represented by
an existing semantic editor remain exact event patterns.

Import sends only the read-only report request. It does not send a mutating
command, reapply the captured state, restart the controller, reset phase,
disable channels, or turn outputs on or off.

## Controller pages

All `/controllers/{id}` pages distinguish desired host configuration from
observed Pico state:

- When host devices exist, show **Configured channels**.
- When host devices are empty and a valid report contains devices, show
  **N channels found on controller**, display the observed IDs, pins, types,
  schedules, and states, and offer the applicable import or provisioning action.
- When a valid report contains an empty device list, show
  **Controller reports 0 channels**.
- When no valid report is available, show
  **Unable to read controller configuration** with the concrete health error.

The existing **No configured pins** message must not conceal reported channels.
Observed channels are clearly marked as observed until import succeeds. Pulse
controls must not treat an observed-but-unimported pin as host-authorized, and a
disabled imported channel cannot be pulsed.

## Settings and later edits

The settings page calls these devices **channels** where that is clearer to the
user. Remove the scheduled-device **Label** column and input entirely. Settings
edits the canonical device ID directly and shows its derived display name; the
device ID is the only editable channel name. Controller and camera label fields
remain unchanged.

Saving controller assignment remains a host operation and does not implicitly
probe or configure hardware. After import, changing a channel ID or enabled
state is a verified runtime configuration transaction, not a firmware reflash.
Unchanged schedules and phases are preserved. Disabling is applied immediately
and verified as off; renaming an ID alone must not toggle an output or reset its
phase.

## Shared operation and agent CLI

Keep the implementation narrow. One shared library operation evaluates or adds
a controller. It discovers the selected serial, reads and validates one fresh
report, decides whether the action is read-only import or provisioning followed
by import, and returns the before/after preview. With `apply=false` it stops
there. With `apply=true` it imports directly unless provisioning was also
explicitly allowed. A required but unauthorized firmware change is an error.
The operation verifies success and commits the host controller. The web service
and direct CLI call this same operation; the browser contains no firmware or
migration logic.

The primary direct CLI supports the complete workflow even when `plamp-web` is
stopped:

```bash
plamp controllers candidates
plamp controllers add plamp8 --serial 9d480174e373e801 --profile plamp8
plamp controllers add plamp8 --serial 9d480174e373e801 --profile plamp8 --apply
plamp controllers add plamp8 --serial 9d480174e373e801 --profile plamp8 --provision --apply
```

`candidates` is non-invasive and uses operating-system enumeration only. `add`
without `--apply` is the explicit read-only inspection and preview. `add` with
`--apply` obtains a new report and permits only read-only hardware import. The
additional `--provision` flag explicitly authorizes firmware and output changes.
There are no interactive prompts, saved plan documents, confirmation tokens, or
a general provisioning framework.

The CLI remains agent-safe: stdout is compact JSON, diagnostics go to stderr,
`--timeout` bounds hardware work, and nonzero exit status indicates failure.
Success states whether hardware changed, whether a reset occurred, whether host
configuration changed, and whether verification passed. Failure identifies the
stage and preserves the recovery evidence path when hardware mutation began.

The web client uses one thin preview/apply REST operation backed by the same
library function. REST is not a dependency of the direct `plamp` command. Both
interfaces use stable USB serials and the existing cross-process Pico and
configuration locks.

## Boundaries

This slice does not add:

- labels to Pico configuration or reports;
- automatic communication with every attached Pico;
- automatic firmware upgrades on discovery or health polling;
- delta reports, configuration checksums, sequence reconstruction, or periodic
  full-snapshot recovery;
- configurable output polarity or safe values;
- support for arbitrary historical scheduler protocols; or
- automatic reconciliation when host and Pico state later diverge.

Complete reports remain the only report format for now.

## Verification

Unit and fake-serial coverage must prove:

- USB enumeration alone performs no serial exchange;
- the explicit add action checks firmware identity before offering import or
  provisioning;
- malformed, unidentified, and unsupported reports do not create host config;
- profile mapping uses pins and produces the eight exact IDs and enabled states;
- device-display humanization is consistent across dashboard and controller
  pages;
- a config rewrite removes obsolete device labels without renaming IDs;
- read-only import sends no Pico command and preserves reported patterns and
  phases;
- import fills the existing serial-matched empty controller instead of creating
  a duplicate;
- disabled GPIO outputs are driven to zero, do not advance, remain off
  after reboot, continue reporting, and reject pulses;
- enabled outputs retain existing scheduling and pulse behavior;
- provisioning preserves schedules by pin for the four enabled Plamp8 outputs;
- configure verification includes `enabled`; and
- every controller-page state has distinct, accurate copy and available
  actions;
- web confirmation refreshes the selected report and stops when the applicable
  action changed;
- direct CLI discovery performs no serial I/O and `controllers add` without
  `--apply` performs only the selected bounded report transaction;
- CLI preview and apply return the same simple result shape;
- CLI stdout remains valid JSON while progress and diagnostics remain on
  stderr; and
- web, REST, and CLI adapters produce the same preview and result from the
  shared operation.

Hardware verification on the installed Plamp8 must be explicitly authorized
because it reflashes and resets the live Pico. Before execution, confirm manual
switch and load safety. Verification then checks the preview, captured backup,
firmware identity, all eight IDs, the four disabled outputs remaining off, the
four enabled schedules being preserved, successful host import, and correct
controller-page display.

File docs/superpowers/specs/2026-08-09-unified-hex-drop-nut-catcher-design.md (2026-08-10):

# Unified Hex-Drop Nut Catcher Design

## Goal

Every Plamp8 nut catcher uses one geometry-producing module: a rectangular insertion tunnel joined to a raised hexagonal entry pocket above a lower hexagonal nut pocket. The nut enters point-first, reaches the raised hex without meeting a flat rear wall, then gravity drops it into the lower hex seat so it cannot rotate while the screw is tightened.

## Geometry

`m3_nut_catcher_negative()` remains the single source of catcher geometry. It creates the hex-cylinder pocket, tunnel, mouth, and optional support-free roofs.

The rectangular insertion tunnel runs from the exterior mouth to the screw axis, where it joins a raised point-first hexagonal entry pocket at the tunnel elevation. The raised hex provides clearance for the complete nut while preserving the pointy rear wall of the catcher. A second hex pocket below it provides the drop and anti-rotation seat. The rectangular tunnel must not extend through the rear half of the hex, because that cuts away the pointy wall and leaves a flat tunnel end.

The drop is proportional to nominal nut thickness:

```scad
nut_drop = nut_thickness * nut_drop_fraction;
```

`nut_drop_fraction` is one globally adjustable parameter and defaults to `1 / 2`. For the 2.38 mm M3 nut profile, this produces a 1.19 mm drop that is clearly visible and spans five complete shelf layers with a 0.20 mm slicer profile. Tunnel clearance does not affect the drop. The tunnel is positioned one `nut_drop` above the pocket floor in the module's local coordinates.

All production callers orient the module so the pocket is below the tunnel in the final assembled orientation. Corner, top-panel, and sub-panel catchers may retain different tunnel widths or thickness clearances, but they do not define separate pocket or drop geometry.

## Printable Roofs

The same module retains its roof-mode parameter. `roof_mode = "30deg"` adds the pointy support-free roofs over the hex pocket and tunnel where required by print orientation. The hex-pocket roof begins at the top of the raised entry hex, `nut_drop + effective_tunnel_h`; beginning it at the lower seat height lets the raised hex cut through the slopes and recreate a flat, floating ceiling. `roof_mode = "flat"` leaves those additions out. Roof selection does not change the pocket, tunnel, or drop calculation.

The adjustment matrix stacks three separately cut coupons in each column. Its final CSG operation must unite the matrix body first and then reapply each cell's shared catcher negative to that united body. Otherwise the coupon above fills the portion of the lower coupon's pointy roof that crosses their common boundary: the top row remains pointy, but the lower rows acquire flat floating ceilings. The catcher negative already extends beyond the exterior tunnel mouth; changing its entry direction or tunnel length does not address this stacked-body boundary.

The sideways diagnostic coupon uses a test-only gable because its printable roof faces a different direction after rotation. That gable must share the tunnel's local floor elevation, `nut_thickness * nut_drop_fraction`; otherwise changing the drop displaces the roof along the sideways tunnel. Its cross-section and 30-degree slopes remain unchanged.

## 45-Degree Test Coupon

The 45-degree diagnostic coupon must expose the complete cross-section of its straight diagonal tunnel through the top, not merely let one corner of the cutter graze the surface. Only this coupon grows: its width increases from 16 mm to 28 mm and its height from 10 mm to 14 mm. The hex pocket remains at its existing datum.

Its label and revision engraving use the effective 14 mm coupon height. They must remain shallow cuts in the actual top face; using the original 10 mm height buries the text inside the coupon and can produce an STL that slicers cannot process.

The tunnel length is derived from the actual coupon top, the unchanged 45-degree catcher origin, and half the 6.1 mm tunnel width:

```scad
opening_edge_distance =
    (effective_coupon_h - origin_45_z) * sqrt(2)
    + corner_nut_tunnel_w / 2
    + boolean_shim;
```

This replaces the guessed 2.5 mm extension, which produced only a minuscule slit. In the all-orientations row, the wider 45-degree coupon shifts by half its added width so it retains the normal gap from its neighbor.

Normal orientation coupons and the clearance matrix retain their existing dimensions. The larger diagnostic coupon does not change any production catcher geometry.

The clearance matrix defaults to three width values and three thickness values: `[-0.1, 0, 0.1]` mm. This produces a compact 3×3 matrix at 0.1 mm intervals while keeping both dimensions independently adjustable from the command line.

The top row has at least 1.0 mm of material above the tallest pointy roof apex. Its coupon height is derived from the active width and thickness offsets plus the adjustable `nut_catcher_test_matrix_roof_cover_t`; it is not a fixed extra-height guess. All three top cells share the height required by the tallest apex so the matrix retains a flat top.

The matrix has no engraved grid. Width and thickness identification remains on the inscription base, where its engraving depth is controlled independently from roof thickness.

## Cleanup

Remove the corner-only absolute drop and the public tunnel-Z-offset parameter. No production catcher may bypass the proportional drop. Orientation helpers may transform the shared module but must not construct alternate catcher geometry.

## Verification

Automated tests will confirm that the shared module computes the half-thickness drop, every production catcher uses it, pointy-roof selection remains available, and only the 45-degree diagnostic coupon receives the larger envelope and geometry-derived straight tunnel. OpenSCAD generation and visual inspection will verify that the complete tunnel cross-section exits the coupon top without warnings or invalid meshes.

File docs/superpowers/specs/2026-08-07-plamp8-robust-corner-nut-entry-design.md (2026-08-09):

# Plamp8 Robust Corner Nut Entry Design

## Problem and physical validation

The north and south wall corner nuts required heat and force to pass through
the 45-degree entry. Before the first revision, the diagonal mouth was 6.10 mm
wide, but only its final 1.5 mm used that width. The rest of the enlarged boss
was traversed through the calibrated 5.65 mm pocket width and 2.42 mm pocket
height. PLA therefore turned the longer tunnel into a tight interference fit.
Heating a completed wall could deform the final hex seat, allowing the nut to
rotate under load.

The first revised PLA coupon widened the complete diagonal tunnel to 6.10 mm
and raised it to 2.52 mm. A nut could then enter approximately 2 mm before
stopping. This distance matches the remaining 0.20 mm retention nibs, which
still derive from the old 5.50 mm throat. The nibs—not the widened rectangular
tunnel—are therefore the remaining insertion obstruction.

## Decision

Treat insertion and anti-rotation as separate fits:

- Keep the final M3 hex pocket width snug: 5.46 mm measured nut width plus
  0.19 mm clearance, producing 5.65 mm across flats. Width prevents rotation.
- Give the corner hex pocket the material-tolerant 0.14 mm thickness
  clearance, producing a 2.52 mm pocket height. Extra axial clearance does not
  permit rotation.
- Use the existing 6.10 mm diagonal mouth width for the complete corner entry
  tunnel, not only its outer detent segment.
- Keep the complete corner entry tunnel at the same 2.52 mm height.
- Disable retention nibs for the 45-degree wall catchers. The nut must reach
  the hex seat by finger pressure without heat or tools.
- Do not add printed plugs. Retaining a nut while handling a loose wall is
  secondary; preventing rotation while tightening the screw is required.
- Apply these tunnel overrides only in `support_free_m3_nut_trap()` and the
  matching 45-degree coupon. Side-loaded panel traps retain their existing
  dimensions.

The shared `m3_nut_catcher_negative()` module gains optional tunnel width and
tunnel height parameters. Their defaults remain the pocket dimensions, so all
existing callers preserve their geometry unless they explicitly request the
corner-entry fit.

The corner adapter additionally supplies its 0.14 mm pocket thickness
clearance and zero nib height. The 45-degree coupon must supply the identical
values. No global M3 fit constant changes.

## Test pieces

The existing `nut_catcher_adjustment_test` set remains the printable test
artifact. Its 45-degree coupons must use the same corner tunnel overrides as
the north and south walls. This avoids calibrating a simplified substitute.
Their labels identify the 6.10 mm tunnel width, 2.52 mm pocket/tunnel height,
and absence of retention nibs.
The generation command is:

```sh
plamp cad generate plamp8 --set nut_catcher_adjustment_test
```

The output revision engraving identifies the source used for the test print.

## Verification

Source-contract tests must fail before implementation and then prove that:

- the canonical catcher exposes independent optional tunnel dimensions;
- the corner trap supplies the 6.10 mm tunnel width, 2.52 mm pocket/tunnel
  height, and zero nib height;
- the 45-degree coupon supplies those same values and labels them;
- ordinary panel trap callers do not opt into the corner dimensions.

Run the Plamp CAD source tests, OpenSCAD syntax/render validation, and generate
the test set before reporting the command to print.

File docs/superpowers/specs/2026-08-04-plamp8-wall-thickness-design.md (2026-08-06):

# Plamp8 wall-thickness design

## Goal

Set the separate Plamp8 enclosure wall thickness with one adjustable 5 mm default without changing the floor or either panel.

## Approach

`wall_thickness` is the single adjustable wall value, with a 5 mm default. Floor thickness, floor fastener geometry, locator interfaces, panel thickness, panel dimensions, and panel fasteners retain their current values. The wall bodies, 45° mitres, and vent cutouts expand outward as `wall_thickness` increases.

For the 30 mm corner screw, the 3 mm floor leaves 27 mm of vertical support. The north/south nut-owner boss and east/west clearance boss each use half: 13.5 mm. Their common boss radius is 6 mm, up from 5 mm, while the screw axis remains fixed.

The nut-entry and retention tunnel height derives from the boss radius, retaining the same 1 mm crown thickness as the boss radius changes.

At the lower corner, the east/west boss starts at the top of the 3 mm floor and ends at 16.5 mm; the north/south boss then runs from 16.5 mm to 30 mm. Neither boss enters the floor.

At the upper corner, the existing north/south nut-owner geometry remains
unchanged. Its nut has a 3.58 mm structural roof. The east/west clearance boss
starts at the sub-panel support plane and extends downward 9.75 mm, ending
exactly where the north/south boss begins. An M3x30 screw passes through the
full nut with about 1.25 mm of tip beyond it. This arrangement allows existing
north/south walls to be reused; only east/west walls need reprinting.

The shared 30 mm screw uses its own lower nut-catcher offset so the catcher stays fully inside the upper end of the north/south 13.5 mm boss; the existing 25 mm floor-stack offset remains unchanged.

## Verification

Validate the part metadata, plan the affected floor/wall/panel views, and generate the wall and assembly views. Confirm that the floor and panel plan variables remain unchanged and that the rendered wall solids are 4 mm thick.

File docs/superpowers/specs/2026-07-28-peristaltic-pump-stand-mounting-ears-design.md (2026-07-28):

# Peristaltic Pump Stand Mounting Ears

## Goal

Move the provisional M5 table-mounting holes from the plate interior to two
external mounting ears, one beyond each end-panel leg.

## Geometry

- Each M5 clearance hole stays on the plate centreline (`y = 0`).
- Each hole sits just outboard of its corresponding leg.
- A circular positive boss around each hole merges with the rectangular plate,
  creating a half-cylindrical ear beyond the plate end.
- The existing central tab slot for each leg remains in the rectangular plate
  material, surrounded on all sides.

## Verification

- The CAD source keeps the M5-hole cutter and uses a named ear radius derived
  from the M5 hole diameter and material margin.
- The plate renders as a simple, non-empty solid.
- The assembly still renders with both end-panel legs seated in their slots.

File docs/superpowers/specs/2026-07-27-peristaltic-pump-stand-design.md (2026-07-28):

# Peristaltic pump stand

## Goal

Create a new Plamp CAD model for a table-standing holder for one or more
peristaltic pumps. The first print targets two pumps.

## Form

- A horizontal top plate carries the pumps.
- Pump motors hang below the plate through circular motor openings.
- Two full-height end panels form a U-stand and keep the motors clear of the
  table.
- The default clearance below the top plate is 55 mm for approximately
  50 mm-long motors.

## Parametric interface

| Variable | Initial value | Meaning |
| --- | ---: | --- |
| `pump_count` | 2 | Number of repeated pump stations. |
| `pump_spacing` | 62 mm | Centre-to-centre spacing of stations. |
| `motor_hole_d` | 29 mm | Circular motor opening diameter. |
| `motor_screw_spacing` | 48.5 mm | M3 mounting-hole centre spacing. |
| `motor_clearance_h` | 55 mm | Plate-to-table clearance. |
| `mount_hole_d` | M5 clearance | Two provisional table-mount holes. |

Each station is aligned on one axis: M3 screw hole, motor opening, M3 screw
hole. The two provisional M5 table-mount holes are placed near the plate ends.

## CAD sets

- `plate`: printable top plate with all pump and table-mount holes.
- `legs`: printable pair of end panels.
- `assembly`: plate plus legs for fit and table-clearance inspection.

## Print and fit intent

- Plate and legs remain separate printable pieces.
- The first version prioritizes stiffness and fit verification over material
  minimization; end panels are full height rather than narrow rails.
- Motor opening and pump fastener dimensions are exposed for later measured
  adjustment.

## Verification

- CAD tests assert the parametric values, repeated station count, and named
  output sets.
- Render `plate`, `legs`, and `assembly`; verify motor openings, M3-hole
  alignment, M5 holes, and 55 mm table clearance.

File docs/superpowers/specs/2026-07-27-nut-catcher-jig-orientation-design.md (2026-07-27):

# Nut Catcher Jig Orientation Design

## Goal

Make each nut-catcher adjustment coupon represent a usable printed catcher orientation.

## Changes

- Make the `45` coupon use the same local transform as the north-wall corner nut catcher, including its support-free flat roof.
- Make `S RF` and `S R30` expose their insertion shafts at the coupon `-Y` edge, like the other one-per-line coupons.
- Keep geometry, labels, candidate values, nibs, and all non-sideways variants unchanged.

## Verification

Add source-level regression checks for the north-canonical 45 transform and the sideways shaft orientation; render the adjustment-test set and inspect the resulting logs.

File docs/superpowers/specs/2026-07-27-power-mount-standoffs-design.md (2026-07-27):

# PSU and DC/DC Mount Standoff Design

## Goal

Guide the PSU and DC/DC M5 screws through the existing 5 mm component raise
while providing load-bearing support at every mounting hole.

## Geometry

A shared mount-standoff module creates 9 mm outside-diameter cylinders at the
existing PSU and converter mount-point coordinates. Each cylinder starts on the
floor's interior surface, rises by `component_raise_h`, and terminates flush
with the existing airflow-support surface.

The existing PSU and converter M5 clearance-hole negatives remain
authoritative. They pass through the floor and the new positive cylinders,
forming coaxial hollow shafts without a second hole-diameter definition. The
PCB or component mounting flange rests on each annular top face; an M5 screw
passes through the shaft and a nut clamps the part against the standoff.

## Consumers

- The assembled/printable box floor includes PSU and converter standoffs when
  `feature_power_screw_mounts` is enabled.
- `psu_footprint` includes the same PSU standoffs.
- `converter_footprint` includes the same converter standoffs.
- Relay mounting geometry is unchanged.

## Verification

- Source tests require one shared 9 mm standoff module and reuse of the
  existing mount-point functions.
- Source tests require the existing M5 negatives to remain the bore source.
- PSU footprint, converter footprint, and floor render as non-empty valid
  solids without OpenSCAD warnings or errors.
- Physical fit and clamping strength remain subject to the next printed
  footprint/floor test.

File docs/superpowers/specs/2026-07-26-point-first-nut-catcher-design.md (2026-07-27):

# Point-First Nut Catcher Design

## Goal

Make the shared M3 nut catcher accept a hex nut in only the intended
orientation and retain it with printable floor nibs.

## Geometry

`m3_nut_catcher_negative()` remains the single authoritative catcher. Its
hexagonal seated pocket has a vertex on the insertion axis. A point-first nut
therefore presents its smaller across-flats dimension across the tunnel and
fits. A nut turned flat-first presents its larger across-corners dimension and
does not fit through the across-flats-sized tunnel.

The seated nut also has a vertex at the back of the pocket. The two existing
angled nibs remain paired around the corresponding rear vertex.

## Printable nibs

Each nib is a solid wedge left in the floor of the subtractive catcher. From
the tunnel entrance toward the pocket, the nut encounters the wedge's gradual
ramp first. After insertion, the steep face retains the nut. The wedge rises
from supported floor material and introduces no downward-facing shelf.

The existing global nib height, length, width, and angle parameters remain the
only fit controls. Panel and corner catchers receive identical pocket and nib
geometry through the shared module.

## Verification

- A source regression test requires vertex-first hex orientation.
- A source regression test requires the nib high edge to be nearer the pocket
  than its floor-only entrance edge.
- Existing shared-dimension and shared-module tests remain green.
- The nut-catcher adjustment jig and NORTH wall render as valid non-empty
  solids without OpenSCAD warnings or errors.
- Physical retention remains subject to the next printed adjustment jig.

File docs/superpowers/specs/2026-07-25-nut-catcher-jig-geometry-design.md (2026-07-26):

# Nut Catcher Jig Geometry Refinement

## Goal

Make the calibration jig accurately exercise the shared production nut catcher while using less plastic and remaining easy to identify, handle, and load.

## Geometry

- Derive the retention nib position from the seated nut center and screw axis. The nut must pass the nib pair before its center reaches the screw axis, then remain retained beneath that axis.
- The 45-degree orientation always uses the flat/open self-supporting roof. Never generate a pointed/30-degree roof at 45 degrees, including when a roof row targets `all`.
- Keep flat and 30-degree roof candidates for the other requested orientations.
- Give the sideways flat-roof candidate a self-supporting teardrop screw passage. Other candidates retain the canonical round screw passage unless their print orientation already transforms it into the required printable geometry.
- Transform each coupon so its nut insertion opening faces negative Y in the exported jig.

## Layout and Material

- Arrange each declarative test row as one connected printable strip.
- Reduce unused material above, below, and beside the functional catcher geometry.
- Tighten label spacing while preserving complete, readable markings and representative wall thickness around the catcher.
- Keep separate rows disconnected so a failed or unwanted row can be discarded independently.

## Generation Legend

OpenSCAD generation output must explain the engraved abbreviations:

- `U`: up
- `D`: down
- `S`: sideways
- `45`: diagonal
- `W`: width clearance
- `T`: thickness clearance
- `RF`: flat roof
- `R30`: 30-degree roof

The legend is emitted once for the adjustment-test set and is recorded in the managed CAD log.

## Verification

- Automated source/geometry-contract tests cover seated nib placement, roof selection, teardrop selection, negative-Y insertion direction, connected row layout, compact dimensions, and legend text.
- A headless OpenSCAD render must complete without warnings or errors and produce simple geometry.
- Mesh connectivity must match the number of declarative rows: one connected component per row.
- Existing C13, XT60, and corner catcher generation must still compile because they share the canonical catcher.

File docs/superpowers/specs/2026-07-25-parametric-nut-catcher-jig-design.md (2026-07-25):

# Parametric Nut Catcher Jig Design

The M3 nut catcher is defined from `nut_across_flats`, `nut_thickness`,
`width_clearance`, `thick_clearance`, and `nib_height`. One canonical local
geometry owns the hex pocket, insertion channel, retention nibs, and optional
roof. Production panel catchers (including C13 and XT60) and wall-corner
catchers call that geometry through coordinate-system wrappers rather than
maintaining independent fit dimensions or nibs.

The canonical catcher uses local X for insertion, local Y across flats, and
local Z for nut thickness/screw axis. `roof_mode` is either `"flat"` (bridge
the small rectangular gap) or `"30deg"` (cut a support-free peaked roof).
Orientation is a fixture concern: `up`, `down`, `sideways`, and `45` rotate the
same catcher relative to the build plate.

The printable `nut_catcher_adjustment_test` set consumes declarative rows of
`[orientation, parameter, mode, candidates]`. `orientation` is one orientation
or `"all"`; `parameter` is `width_clearance`, `thick_clearance`, or
`roof_mode`; `mode` is `offsets` for numeric deltas from the initial value and
`values` for literal candidates. Rows are independent sweeps, never a Cartesian
product. Every coupon is engraved with orientation, varied parameter/value,
and the revision. Defaults exercise five width offsets and five thickness
offsets on `up`, plus both roof modes in every orientation.

The production defaults remain the measured 5.46 mm across-flats, 2.38 mm
thickness, 0.14 mm width clearance, 0.14 mm thickness clearance, and 0.20 mm
nib height established by revision `83e9554`.

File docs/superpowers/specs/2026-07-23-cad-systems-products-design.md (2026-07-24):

# CAD Systems, Products, Models, and Manufacturing Metadata

**Date:** 2026-07-23

## Goal

Replace the current part/view/preset vocabulary with a CAD structure that matches
how humans design and manufacture complete systems:

- a **system** catalogs reusable libraries, models, profiles, and a nested product
  tree;
- a **product** combines model sets and other products into something a human
  intends to manufacture, inspect, or maintain;
- a **model** is one coherent OpenSCAD source graph;
- a **set** is the smallest selectable unit in a model and arranges one or more
  physical parts;
- a **part** is a physical component implemented as a named OpenSCAD module;
- a **feature** is reusable constructive or subtractive geometry used by parts;
  and
- an **artifact** is a generated geometry file, preview, log, manifest, README,
  or other run output.

The design keeps OpenSCAD files ordinary and directly usable. Plamp-specific
descriptions and manufacturing metadata move into adjacent JSON sidecars and a
system manifest. Native OpenSCAD parameter presets are not part of this model.

This is a pre-1.0 vocabulary and schema replacement. The implementation removes
the old names rather than carrying compatibility aliases.

## Why the Current Vocabulary Fails

The current CLI calls a root SCAD directory a `part`, although `plamp8.scad`
contains many physical parts. A current `view` may arrange several parts, such
as north and south walls. A current `preset` is actually an ordered generation
composition, while OpenSCAD already uses “preset” for saved parameter values.

The current embedded `generate.json` also mixes four responsibilities:

- the SCAD model's selectable geometry;
- human descriptions;
- grouping and orchestration;
- generation-variable defaults.

That structure cannot describe a complete Plamp installation containing the
controller enclosure, Raspberry Pi holder, and camera holder without pretending
they belong in one SCAD file.

## Terminology and Ownership

### System

A system is the top-level CAD catalog for one repository or independently
versioned design workspace. It owns:

- model names and model-sidecar paths;
- declared shared libraries;
- named printer, nozzle, material, and quality profiles;
- named products and their nesting; and
- the default product, when one exists.

Only a system may compose multiple models. A system is not itself a generated
geometry object.

### Product

A product is an ordered list of model/set references and/or nested product
references. It may contain multiple sets from one model, sets from several
models, or only one set. Allowing a one-model product is useful for replacement
parts, validation suites, and migration of current presets; the important rule
is that cross-model composition occurs only at the product layer.

Products may carry variables, slicing policy, descriptions, and reference-local
overrides. Product nesting is acyclic and preserves declared order.

Examples include:

- `complete`: enclosure, Raspberry Pi holder, and camera holder;
- `split-box`: the printable Plamp8 enclosure sets;
- `panels`: replacement top and sub-panel sets;
- `fit-and-function`: component, connector, and fastener validation sets; and
- `assembly`: illustrated non-printable assembly sets.

### Model

A model is one root SCAD file plus its local source and asset graph. The root may
`use`, `include`, or `import` other files. A model is portable as a folder and has
an optional adjacent Plamp model sidecar.

The model owns its set selector, parts, features, and canonical SCAD variable
definitions. A model does not know which other models are manufactured with it.

### Set

A set is the smallest public CAD selection. It is an ordinary top-level SCAD
Customizer variable named `set`:

```scad
set = ""; // [floor, panels, fit-and-function, assembly]
```

The assignment and its ordered Customizer choices are authoritative. Plamp reads
that declaration. The assigned empty string is the default even though it is not
repeated as a Customizer choice. A named set arranges one or more parts for one
OpenSCAD invocation. A set may contain a single part. Parts are not independently
selectable through the public Plamp CAD interface.

The empty set is valid and means normal OpenSCAD top-level behavior. A model
without a set declaration also remains generatable as one implicit empty-set
job.

One set invocation produces one primary geometry artifact. That artifact may
contain several disconnected printable pieces. Products produce several primary
geometry artifacts by expanding to several set invocations.

### Part

A part is a named OpenSCAD module representing a physical component. The normal
Plamp convention is a difference between positive and negative geometry:

```scad
module top_panel_part() {
    difference() {
        top_panel_positive();
        top_panel_negative();
    }
}
```

This is a source convention, not a parser contract. Plamp does not attempt to
infer physical parts by parsing arbitrary OpenSCAD module bodies.

### Feature and Library Feature

A feature is a reusable module that contributes constructive or subtractive
geometry, such as a countersink, nut catcher, rib, label pocket, or connector
cutout. A library feature is a feature exported for reuse across models. Private
modules that are neither parts nor reusable features are simply helpers.

Libraries may also expose functions and constants. Libraries do not own sets or
products and are not generated directly.

### Artifact, Job, Plan, and Run

- A **job** is one resolved model/set invocation with effective CAD variables and
  manufacturing advice.
- A **plan** is the deterministic ordered expansion of a model selection or
  product into jobs.
- A **run** executes a plan and owns its archived inputs and outputs.
- An **artifact** is any generated file. Geometry artifacts, logs, manifests,
  READMEs, and previews remain distinct artifact types.

Existing source archiving, fingerprints, readable run IDs, regeneration,
cataloging, and log behavior remain. Fingerprints use the new system/product/
model/set identity and effective geometry variables.

## File Layout

The default repository layout is:

```text
cad/
├── plamp.system.cad.json
├── workshop-jigs.system.cad.json
└── profiles/
    ├── bambu-x1c.json
    ├── nozzle-0.4mm.json
    ├── petg.json
    └── draft.json

things/
├── plamp8/
│   ├── plamp8.scad
│   ├── plamp8.cad.json
│   └── local-library/
├── rpi-holder/
│   ├── rpi-holder.scad
│   └── rpi-holder.cad.json
└── camera-holder/
    ├── camera-holder.scad
    └── camera-holder.cad.json
```

The names are defaults, not requirements that source folders be named
`things`. The system manifest resolves model sidecars by repository-relative
path. A sidecar resolves its root SCAD file and local paths relative to the
sidecar directory.

By default, `plamp cad` discovers every `*.system.cad.json` file directly inside
the repository's `cad/` directory. Multiple system manifests may live beside
one another and may reference the same model sidecars. Discovery is not
recursive: a manifest outside that directory is selected by explicit path rather
than being silently folded into the repository catalog.

Every system-aware command accepts `--system SYSTEM`, where `SYSTEM` is either a
unique declared system name or an explicit manifest path. An explicit path may
point outside the default `cad/` directory when normal path authorization rules
allow it. Commands record the resolved manifest path and content hash. Plamp
never combines system manifests into an implicit larger system.

When `--system` is omitted, one discovered system is selected automatically. If
several exist, an interactive terminal offers a system menu; a non-interactive
command fails with the discovered names and an exact `--system` example. A local
default system may remove the prompt, but the command prints the selected system
and the run manifest records it.

SCAD files contain no embedded `generate.json`. Model folders remain portable
because their sidecar travels with the source folder.

## Clean OpenSCAD Contract

The root SCAD file remains directly usable in OpenSCAD:

```scad
render_fn = 96;
render_text = true;
$fn = render_fn;

set = ""; // ["", floor, top_panel, sub_panel, assembly]

if (set == "floor")
    floor_set();
else if (set == "top_panel")
    top_panel_set();
else if (set == "sub_panel")
    sub_panel_set();
else if (set == "assembly")
    assembly_set();
else
    default_model();
```

The OpenSCAD Customizer exposes `set` and all normal model variables. A human can
select a set in OpenSCAD or let the empty set render normal top-level geometry.

Plamp deliberately ignores OpenSCAD native parameter preset files and does not
invoke `openscad -p ... -P ...`. Effective values are resolved by Plamp and
passed as explicit `-D NAME=VALUE` arguments. Native presets remain available to
someone using OpenSCAD independently, but they have no Plamp generation meaning.

## Model Sidecar

The adjacent sidecar provides descriptions and Plamp manufacturing metadata
without redefining geometry:

```json
{
  "schema": "plamp-cad-model/1",
  "name": "plamp8",
  "source": "plamp8.scad",
  "description": "Plamp8 controller enclosure",
  "sets": {
    "": {
      "description": "Normal OpenSCAD model output"
    },
    "floor": {
      "description": "Printable enclosure floor",
      "slicing": {
        "orientation": "as-exported",
        "supports": "forbidden"
      }
    },
    "top_panel": {
      "description": "Printable top panel",
      "slicing": {
        "orientation": "as-exported",
        "ironing": "recommended",
        "supports": "forbidden"
      }
    },
    "assembly": {
      "description": "Complete illustrated enclosure assembly",
      "printable": false
    }
  }
}
```

The sidecar is optional. Without one, Plamp lists the Customizer set names and
generates them without descriptions or structured recommendations.

When a sidecar exists:

- its source path must remain inside the model folder;
- every sidecar set must exist in the authoritative SCAD set choices, including
  `""` when described;
- every declared SCAD set need not have metadata, but validation reports missing
  descriptions as an advisory diagnostic;
- unknown metadata keys fail schema validation; and
- the sidecar may assign model and set defaults but may not introduce a set that
  the SCAD source cannot select.

Model- and set-level `variables`, when present, are Plamp generation overrides.
They do not redefine a variable or its canonical SCAD default. A sidecar should
omit assignments that merely repeat the source value.

Canonical set descriptions live only in the model sidecar. Product entries may
add contextual notes but do not redefine them.

## System and Product Manifest

The system manifest catalogs models, libraries, profiles, and products:

```json
{
  "schema": "plamp-cad-system/1",
  "name": "plamp",
  "description": "Plamp hydroponics automation hardware",
  "models": {
    "plamp8": "things/plamp8/plamp8.cad.json",
    "rpi-holder": "things/rpi-holder/rpi-holder.cad.json",
    "camera-holder": "things/camera-holder/camera-holder.cad.json"
  },
  "libraries": {
    "BOSL2": {
      "path": "vendor/BOSL2",
      "license": "BSD-2-Clause"
    }
  },
  "profiles": {
    "bambu-x1c": "cad/profiles/bambu-x1c.json",
    "nozzle-0.4mm": "cad/profiles/nozzle-0.4mm.json",
    "petg": "cad/profiles/petg.json",
    "draft": "cad/profiles/draft.json"
  },
  "default_product": "complete",
  "products": {
    "component-floorplans": {
      "description": "Component mounting footprint tests",
      "items": [
        {"model": "plamp8", "set": "relay_footprint"},
        {"model": "plamp8", "set": "psu_footprint"},
        {"model": "plamp8", "set": "converter_footprint"}
      ]
    },
    "top-panel-fit": {
      "description": "Top-panel connector fit tests",
      "items": [
        {"model": "plamp8", "set": "ac_duplex_panel"},
        {"model": "plamp8", "set": "dc_connector_panel"},
        {"model": "plamp8", "set": "usb_c_panel"},
        {"model": "plamp8", "set": "c13_panel"}
      ]
    },
    "corner-coupons": {
      "description": "Panel and wall corner fastener tests",
      "items": [
        {"model": "plamp8", "set": "panel_corner_fastener_test"},
        {"model": "plamp8", "set": "corner_coupon"},
        {"model": "plamp8", "set": "wall_corner_fastener_assembly"}
      ]
    },
    "split-box": {
      "description": "Printable Plamp8 enclosure as separate pieces",
      "items": [
        {"model": "plamp8", "set": "floor"},
        {"model": "plamp8", "set": "north_south_walls"},
        {"model": "plamp8", "set": "east_west_walls"},
        {"model": "plamp8", "set": "top_panel"},
        {"model": "plamp8", "set": "sub_panel"}
      ]
    },
    "fit-and-function": {
      "description": "Component, connector, and fastener validation",
      "items": [
        {"product": "component-floorplans"},
        {"product": "top-panel-fit"},
        {"product": "corner-coupons"}
      ]
    },
    "complete": {
      "description": "Complete Plamp hardware",
      "items": [
        {"product": "split-box"},
        {"model": "rpi-holder", "set": "standard"},
        {"model": "camera-holder", "set": "wall-mount"}
      ]
    }
  }
}
```

This manifest example shows the intended end state after the Raspberry Pi and
camera holder models exist. The initial repository manifest must list only model
paths that are present and valid; it may use `split-box` as its default product
until `complete` can resolve. Missing future models are not represented by
placeholders that weaken validation.

A product item contains exactly one of `product` or `model` plus `set`. It may
also contain:

- `description` or `note` for product-local context;
- `variant` when the same set appears with different effective values;
- `variables` for that reference;
- `slicing` requirements or recommendations; and
- `profiles` to add profiles for that subtree.

Sibling items that directly reference the same model/set with different item
assignments must provide distinct `variant` labels. The label is part of the
human artifact identity and product path, but not the geometry fingerprint;
identical geometry can still be reused across variants.

Product expansion:

- preserves item order;
- permits arbitrary practical nesting depth;
- rejects cycles with the complete product path;
- permits repeated model/set references with different variables;
- deduplicates identical resolved geometry jobs by complete fingerprint while
  retaining every product-membership path; and
- does not require a product to span more than one model.

## Variable Definitions and Assignments

The SCAD source owns variable definitions, canonical values, Customizer widgets,
and allowed-value comments:

```scad
wall_t = 2.4;          // [1.6:0.2:4]
hole_clearance = 0.25; // [0:0.05:0.8]
render_fn = 96;        // [12:4:128]
```

External files assign values; they do not duplicate a complete variable schema.
Plamp passes only resolved assignments as `-D` expressions. The system records
typed values and preserves explicitly authorized raw OpenSCAD expressions using
the existing raw-define contract.

For one leaf job, low-to-high precedence is:

1. SCAD source defaults;
2. model-sidecar variables;
3. set-sidecar variables;
4. selected profiles in declared and command-line order;
5. product layers from the deepest product outward to the explicitly selected
   top-level product; and
6. explicit CLI overrides.

A product layer applies the product's own `variables`, then the variables on the
item by which its parent selected that product or leaf set. Therefore an item
override is local to that item and wins over variables declared directly on the
same product. As resolution moves outward, the parent product and its item
override may intentionally replace a child value. This makes the selected
top-level product the final structural authority before the CLI.

For example, if `complete` includes `split-box`, and `split-box` includes the
`top_panel` set, the job resolves in this order:

```text
SCAD -> model -> top_panel set -> profiles
     -> split-box -> split-box's top_panel item
     -> complete -> complete's split-box item -> CLI
```

Product policy therefore overrides reusable model/set/profile defaults, and a
reference-local value overrides its containing product for that subtree. The
manifest records each contributing layer and the winning value with provenance.

No separate `configuration` object exists. A configuration would merely be
another variable container; products, scoped assignments, and profiles already
provide the required structure.

## Orthogonal Manufacturing Profiles

Profiles describe how and where geometry is manufactured rather than what the
product contains. The initial profile kinds are:

- `printer`: build volume and printer-specific calibration;
- `nozzle`: nozzle diameter and nozzle-dependent limits;
- `material`: shrinkage, fit compensation, and material guidance; and
- `quality`: draft/production geometry quality and slicing preferences.

Profiles are composable ordered overlays. They may contribute CAD values and
slicing metadata:

```json
{
  "schema": "plamp-cad-profile/1",
  "name": "petg",
  "kind": "material",
  "cad": {
    "hole_clearance": 0.35,
    "press_fit_clearance": 0.20
  },
  "slicing": {
    "material": "PETG",
    "ironing": "discouraged"
  }
}
```

Profile names and content hashes are part of run provenance. Profile CAD values
affect geometry fingerprints. Slicing-only changes do not invalidate an existing
geometry artifact; they change the manufacturing metadata fingerprint and
generated README.

The profile list for a leaf job is assembled in this order: configured local
defaults, profiles on the selected top-level product, profiles encountered on
product and item references while walking from root to leaf, profiles on the
model/set selection, and explicit command-line profiles. This establishes a
deterministic list before the variable precedence rules apply it.

System profiles may be versioned in the repository. Instance-local profiles and
the human's default printer/material selection live under `PLAMP_DATA_DIR` and
are not committed. System and local profile IDs occupy separate namespaces,
such as `system:petg` and `local:my-petg`, so workstation data cannot silently
shadow a versioned profile.

A normal human command uses configured local default profiles and prints which
ones were selected. Each repeated `--profile` appends after those defaults;
later profiles win scalar conflicts. `--no-default-profiles` disables the local
defaults for a fully explicit run. CLI variable overrides remain final.

Profiles should use separate `cad`, `slicing`, and `machine` namespaces where
possible. A profile does not silently weaken a hard product/set manufacturing
constraint.

## Slicing and Manufacturing Metadata

Slicing metadata starts as portable structured advice, not slicer automation.
The canonical data is stored in sidecars, products, profiles, and run manifests.
Every run renders the resolved advice into its human README.

Initial portable keys include:

- `orientation`: `as-exported` or a human instruction;
- `supports`: `required`, `recommended`, `optional`, `discouraged`, or
  `forbidden`;
- `support_style`: portable advice such as `build-plate-only`;
- `ironing`: the same recommendation vocabulary;
- `material`;
- `layer_height` or maximum layer height;
- minimum wall/perimeter count;
- brim/adhesion advice; and
- free-form ordered notes.

Example README output:

```text
top_panel

Recommended slicing:
- Use the exported orientation.
- Enable ironing.
- Do not generate supports.
- Keep the engraved face upward.
```

Requirements and preferences are distinct. Conflicting hard requirements fail
planning with provenance rather than silently choosing one. Printer profiles may
refine recommendations but cannot weaken `required` or `forbidden` constraints.

The first implementation does not emit BambuStudio, PrusaSlicer, Cura, or 3MF
settings. Later adapters may translate portable metadata into slicer-specific
profiles. Core metadata must not begin with vendor field names.

When parts inside one set need incompatible object-specific slicing policy, the
model should expose separate sets/artifacts, or a later multi-object 3MF design
must preserve object identity. A plain STL containing disconnected shells is not
treated as sufficient object-level policy transport.

## Libraries and Reproducible Dependency Staging

OpenSCAD source-code dependencies use `use <...>` and `include <...>`; geometry
assets use `import(...)`. Generation must stage both kinds. OpenSCAD resolves
non-absolute library references relative to the calling SCAD file, then declared
library paths, user/built-in library locations, and installation locations.
Relying on the workstation's unresolved library search path would make archived
runs non-reproducible.

The current generator already archives the complete local model folder. The new
dependency flow is:

1. Resolve the selected model source at the requested Git revision or explicitly
   labelled dirty working tree.
2. Ask OpenSCAD to produce its make-style dependency file with `-d` for a cheap
   dependency-discovery pass using the source environment.
3. Resolve and classify every transitive source and imported asset.
4. Keep model-local files through the existing complete-folder snapshot.
5. Archive repository-local dependencies from the same Git revision, never from
   the unrelated current working tree.
6. Copy declared external/shared and referenced OpenSCAD installation libraries
   into the run staging directory while preserving each library root and
   internal relative paths.
7. Copy external imported assets into deterministic staged roots.
8. Invoke the actual render with a sanitized `OPENSCADPATH` containing only the
   staged library roots. The render must not consult live user or installation
   library directories.
9. Produce and compare a second dependency file from the staged render. Any
   unresolved, escaped, or newly host-resolved dependency fails the job.

The staged archive records for each dependency:

- logical library or asset name;
- classification: model-local, repository-local, declared shared, built-in, or
  imported asset;
- archive-relative path;
- content hash;
- Git origin/revision when known;
- license metadata when declared; and
- the OpenSCAD version and effective sanitized library path.

Absolute paths outside approved roots, unsafe symlinks, missing dependencies,
cycles that OpenSCAD cannot resolve, and undeclared shared libraries fail with
actionable diagnostics.

A shared library such as BOSL2 can be declared once by the system and then used
by models for illustrated screws, nuts, washers, threads, and other assembly
context. The first implementation enables deterministic library use; converting
existing Plamp8 hand-written fastener illustrations to BOSL2 is separate CAD
work and is not required by this migration.

## CLI Contract

The human-facing discovery commands become:

```bash
plamp cad systems
plamp cad models --system plamp
plamp cad sets plamp8 --system plamp
plamp cad products --system plamp
plamp cad profiles --system plamp
plamp cad libraries --system plamp
plamp cad templates
```

`systems` lists every discovered system with its declared name, description,
manifest path, and default product. `models` lists every model registered by the
selected system with its model ID, description, sidecar path, and root SCAD
path. `sets MODEL` lists every authoritative SCAD set for that model, including
the empty/default set, with its description, printable status, and source model.
Descriptions appear in the default human output as well as interactive and JSON
output. No system, model, or set may be reachable for generation while absent
from the corresponding navigation command.

Stable navigation IDs are the declared system name, the model key inside that
system, and the SCAD set value. Invalid discovered manifests or broken catalog
entries remain visible with an invalid status and diagnostic instead of
silently disappearing; they cannot be selected for generation until repaired.
A valid entry without an optional description displays `(no description)` and
produces the existing advisory diagnostic rather than leaving an unlabeled row.

All discovery commands support the same human-readable and `--json` forms. JSON
rows contain explicit `kind`, stable ID, parent system/model IDs, description,
and source path so callers can navigate without parsing display text.

The simplest planning and generation commands use the system's declared default
product:

```bash
plamp cad plan
plamp cad generate
plamp cad generate --system plamp
```

They print the selected product before doing work. If the system has no default
product, the interactive terminal offers the product menu and a non-interactive
invocation fails with a command showing how to select `--product`.

Direct model generation is the advanced path:

```bash
plamp cad plan plamp8 --set top_panel
plamp cad generate plamp8 --set top_panel
plamp cad generate plamp8 --system plamp
```

Omitting `--set` selects the model's empty/default set. Product generation is
explicit:

```bash
plamp cad plan --product complete
plamp cad generate --product complete
plamp cad generate --product fit-and-function --profile draft
```

Profile IDs may be written without their namespace when exactly one profile with
that short name is visible. Ambiguity is an error that lists the qualified IDs.

`plan` remains the read-only expansion and validation surface. `generate`
performs the same planning internally before rendering; humans do not need to
run `plan` first.

The interactive menu starts with system selection when necessary, then lists
that system's models and products in separate sections. Selecting a model opens
its complete set list. Descriptions and stable IDs are shown at every level;
back-navigation never discards the selected system. Human output remains the
default, with `--json` for machines.

The migration removes:

- `plamp cad views` in favor of `plamp cad sets`;
- `--view` and `--view-define` in favor of `--set` and `--set-define`;
- `--preset` and all synthetic presets;
- `plamp cad new --list-templates` in favor of `plamp cad templates`;
- the embedded `generate.json` block; and
- the public word `part` for root models.

There are no compatibility aliases before 1.0. Diagnostics show the replacement
command when detecting an obsolete invocation.
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

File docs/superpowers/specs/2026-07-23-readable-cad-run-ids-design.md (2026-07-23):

# Readable CAD Run IDs and Regeneration

## Goal

Make managed `plamp cad generate` archives easy for a person to recognize while
preventing accidental duplicate renders of the same CAD selection and source on
the same day.

## Run ID

A managed run ID uses:

```text
<year>-<lowercase-month><day>-<part>-<selector>-<hour>h:<minute>m-<revision>
```

For example:

```text
2026-jul23-plamp8-top_panel-22h:19m-47e7d26
```

The date and time use the workstation's local timezone and omit seconds. The
selector is the preset name, the single view name, or `views` for an explicit
multi-view selection. The revision remains the short Git revision for clean
committed source and the explicit revision label for dirty source. Existing
component sanitization still applies to part, selector, and revision strings.
Manifest timestamps remain UTC ISO-8601 values.

Because OpenSCAD renders normally take longer than one minute, two genuinely
different runs are not expected to request the same readable path sequentially.
If that rare path collision occurs, generation fails clearly instead of adding
a random or numeric suffix.
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

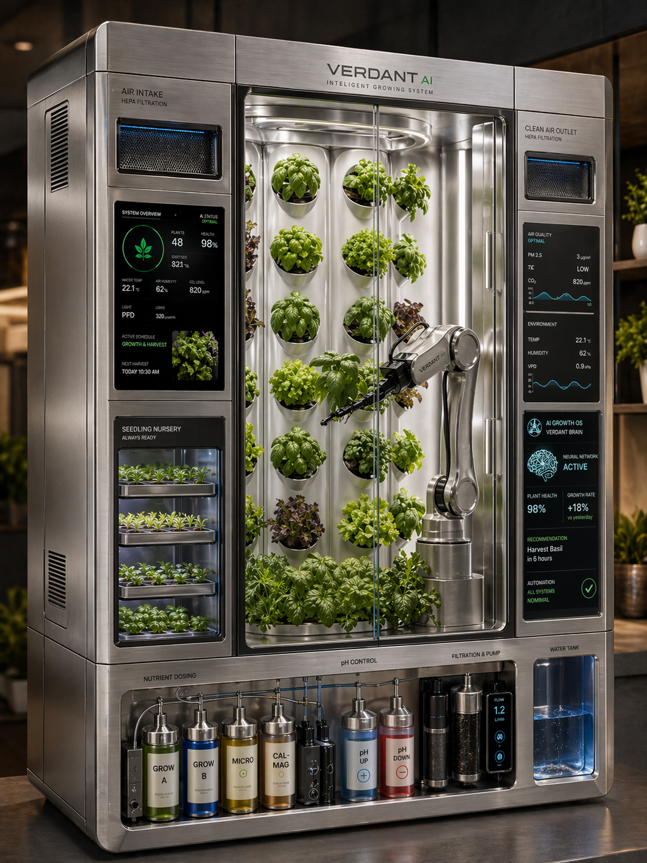
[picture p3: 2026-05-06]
docs/images/agri-factory.png

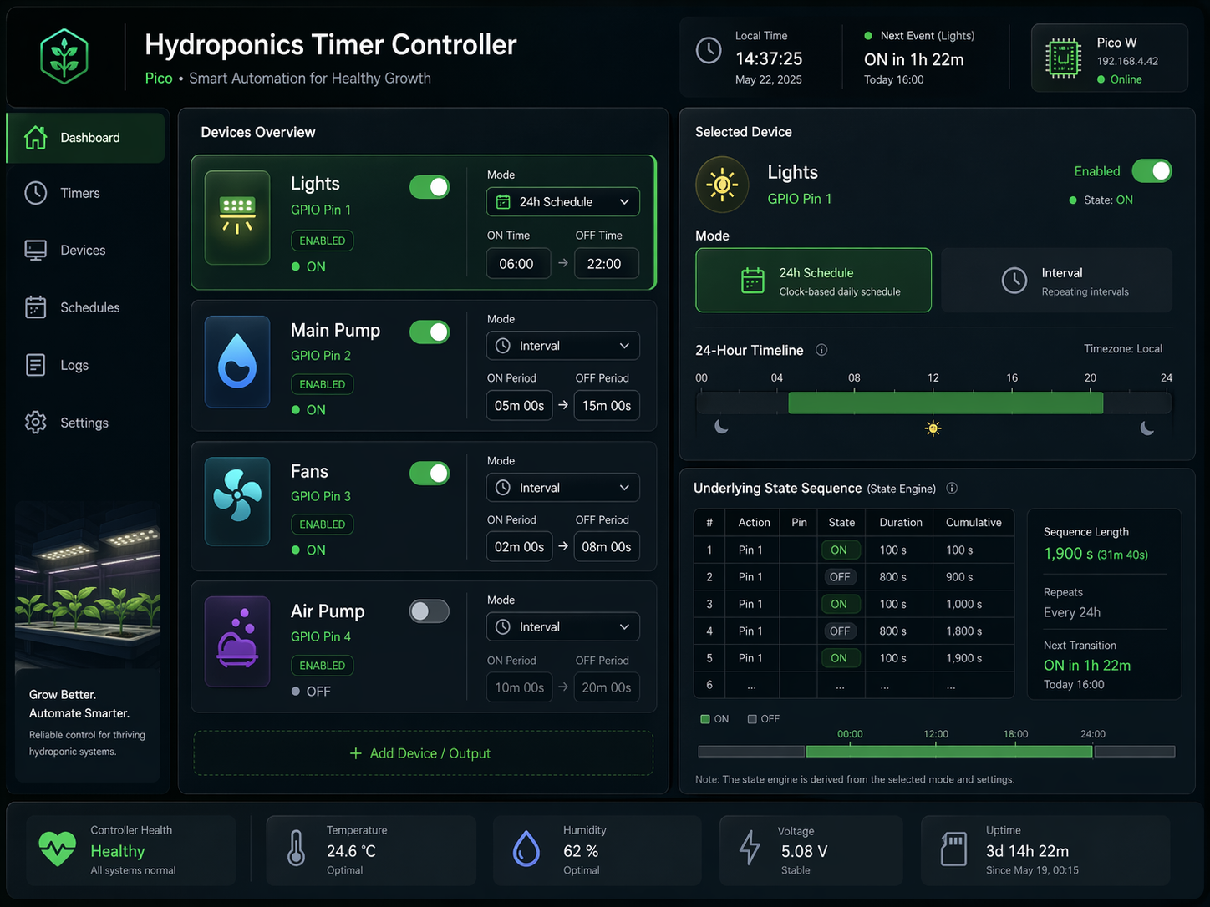
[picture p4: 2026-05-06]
docs/images/agri-ui.png

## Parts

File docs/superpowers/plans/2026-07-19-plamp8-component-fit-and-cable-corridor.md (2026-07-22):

# Plamp8 Component Fit and Cable Corridor Implementation Plan

> **For agentic workers:** REQUIRED SUB-SKILL: Use superpowers:subagent-driven-development (recommended) or superpowers:executing-plans to implement this plan task-by-task. Steps use checkbox (`- [ ]`) syntax for tracking.

**Goal:** Loosen the DC/DC converter retaining pocket by 0.5 mm overall in each axis and create a wider relay-to-PSU corridor for the USB connector and upward cable bend.

**Architecture:** Change only the three existing parametric inputs that already drive the relevant geometry. The converter's calibrated body and mount definitions remain fixed, while the shared PSU and relay X offsets move their complete floor and illustration feature groups together.

**Tech Stack:** OpenSCAD, the direct `plamp cad` CLI, Git

## Global Constraints

- Set `converter_fit_clearance = 0.75`; do not change `converter_w`, `converter_d`, mount spacing, mount holes, airflow-post layout, or transparent converter keepout.
- Set `internal_psu_x = 70`, moving the complete PSU group 10 mm east.
- Set `internal_relay_x = -39`, moving the complete relay group 4 mm west.
- Do not change any component Y offset or move the DC/DC converter.
- Add no automated test for these user-directed fit changes.
- Push the source commit before running OpenSCAD.
- Render only through `plamp cad generate` and leave generated files outside the repository.
- Do not push this checkpoint to `main` until the user approves the rendered geometry.

---

### Task 1: Adjust component fit and placement

**Files:**
- Modify: `things/plamp8/plamp8.scad`

**Interfaces:**
- Consumes: `converter_retaining_w`, `converter_retaining_d`, and every existing floor/illustration transform based on `internal_psu_x` or `internal_relay_x`.
- Produces: a converter retaining envelope 0.5 mm larger overall in X and Y, plus a relay-to-PSU body corridor approximately 46 mm wide.

- [ ] **Step 1: Confirm the worktree contains only the committed design**

Run:

```bash
git status --short
git branch --show-current
```

Expected: no status output and branch `feature/plamp8-flat-walls`.

- [ ] **Step 2: Change only the three approved parameters**

In `things/plamp8/plamp8.scad`, make these exact replacements:

```scad
converter_fit_clearance = 0.75;
```

```scad
internal_psu_x = 70;
```

```scad
internal_relay_x = -39;
```

Do not edit `converter_w`, `converter_d`, `internal_converter_x`, `internal_psu_y`, `internal_relay_y`, or any geometry module.

- [ ] **Step 3: Verify the source diff is limited to those values**

Run:

```bash
git diff --check
git diff -- things/plamp8/plamp8.scad
```

Expected: `git diff --check` is silent, and the SCAD diff contains exactly three changed assignment lines: `0.5 → 0.75`, `60 → 70`, and `-35 → -39`.

- [ ] **Step 4: Commit and push before OpenSCAD**

```bash
git add things/plamp8/plamp8.scad
git commit -m "Loosen Plamp8 component fit"
git push origin feature/plamp8-flat-walls
```

Expected: the commit succeeds and the remote feature branch advances. Do not invoke OpenSCAD before this step completes.

- [ ] **Step 5: Render the converter footprint from the pushed clean commit**

Run from `things/plamp8`:

```bash
fit_preview_root="$(mktemp -d)"
plamp cad generate plamp8 --view converter_footprint --output "$fit_preview_root/converter"
converter_revision="$(git rev-parse --short HEAD)"
test -s "$fit_preview_root/converter/plamp8_converter_footprint_${converter_revision}.stl"
! rg -n "WARNING|ERROR|empty top level object" "$fit_preview_root/converter/readme.md"
```

Expected: the converter STL is non-empty and the log contains no warning, error, or empty-object match. The body and two mount holes remain fixed while all four retaining corners move 0.25 mm outward per side in both axes.

- [ ] **Step 6: Render the complete assembly from the same pushed commit**

Using the same `fit_preview_root` and `converter_revision` values:

```bash
plamp cad generate plamp8 --view assembly --output "$fit_preview_root/assembly"
test -s "$fit_preview_root/assembly/plamp8_assembly_${converter_revision}.stl"
! rg -n "WARNING|ERROR|empty top level object" "$fit_preview_root/assembly/readme.md"
```

Expected: the assembly STL is non-empty and the log contains no warning, error, or empty-object match. Visual inspection confirms the PSU group moved 10 mm east, the relay group moved 4 mm west, their associated mounts/retainers/keepouts remain aligned, and the new corridor is clear for the USB connector and upward cable bend.

- [ ] **Step 7: Report the pushed commit for visual approval**

Run:

```bash
git status --short
git log -1 --oneline
```

Expected: the worktree is clean. Report the feature commit and wait for user approval before fast-forwarding `main`.

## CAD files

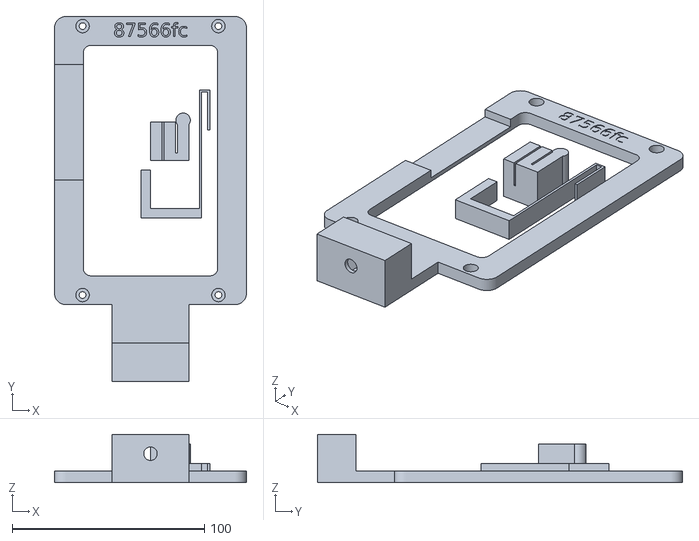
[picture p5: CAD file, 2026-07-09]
things/plamp_stand/prints/jul09_955c771/plamp_stand_assembly_87566fc.stl
100.0 x 190.0 x 25.0

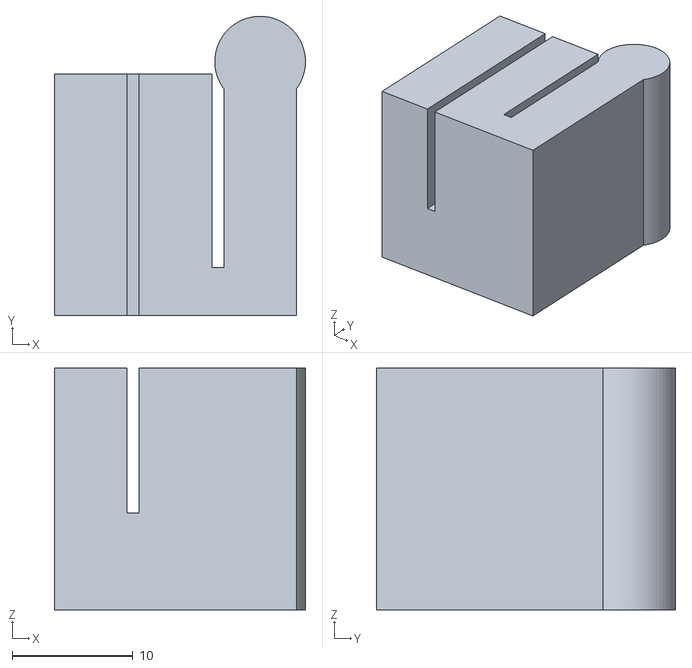
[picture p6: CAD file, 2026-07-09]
things/plamp_stand/prints/jul09_955c771/plamp_stand_camera_clip_87566fc.stl
20.8 x 24.8 x 20.0

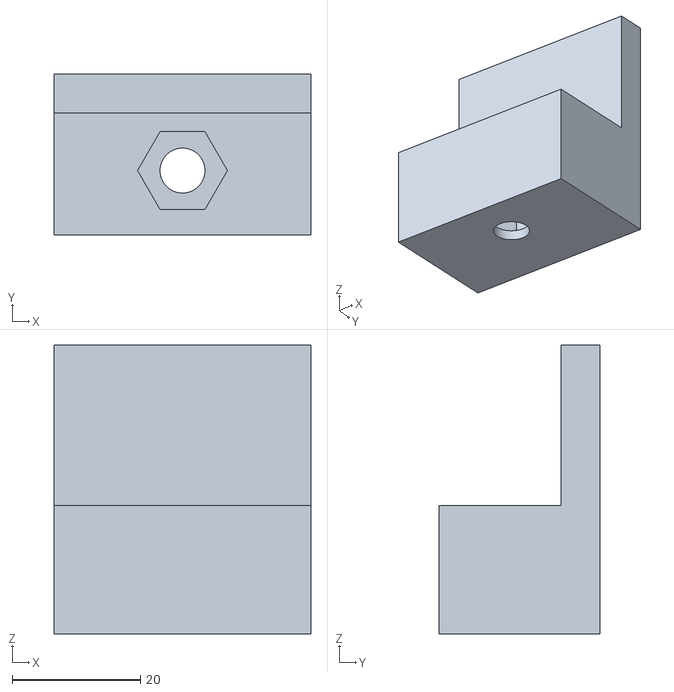
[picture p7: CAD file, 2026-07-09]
things/plamp_stand/prints/jul09_955c771/plamp_stand_tripod_87566fc.stl
40.0 x 25.0 x 45.0

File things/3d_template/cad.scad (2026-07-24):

render_fn = 64;
$fn = render_fn;
set = "__PLAMP_PART__"; // [__PLAMP_PART__, assembly]

part_w = 40;
part_d = 30;
part_h = 4;
boolean_overlap = 0.1;

module __PLAMP_PART___positive() {
    cube([part_w, part_d, part_h], center = true);
}

module __PLAMP_PART___negative() {
    echo("BOM", "M3x16 screw", 1);
    cylinder(d = 3.4, h = part_h + 2 * boolean_overlap, center = true);
}

module __PLAMP_PART__() {
    difference() {
        __PLAMP_PART___positive();
        __PLAMP_PART___negative();
    }
}

if (set == "__PLAMP_PART__") {
    __PLAMP_PART__();
} else if (set == "assembly") {
    __PLAMP_PART__();
}

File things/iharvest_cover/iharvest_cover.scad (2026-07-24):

$fn = 128;
set = ""; // [assembly, plate]

revision_string = "dev";

// -------- dimensions --------
W = 196.85; // 7.75 * 25.4
D = 165.10; // 6.50 * 25.4

plate_thick = 4;

// Sagitta: how much the arc middle drops below its endpoints.
top_sag = 10;
bottom_sag = 6.35;

corner_r = 6;

// holes
air_hole_d = 10;
wire_hole_d = 12;

N = 96;

// engraving
engrave_size = 5;
engrave_depth = 0.6;


// -------- arc math --------
function arc_radius(w, sag) =
    sag == 0 ? 1e9 : (w * w) / (8 * sag) + sag / 2;

function arc_y_center_below(x, y_edge, w, sag) =
    let(
        R = arc_radius(w, sag),
        yc = y_edge - R + sag
    )
    yc + sqrt(R * R - x * x);

function y_top(x) = arc_y_center_below(x, D / 2, W, top_sag);
function y_bottom(x) = arc_y_center_below(x, -D / 2, W, bottom_sag);


module cover_outline_raw_2d() {
    polygon(
        points = concat(
            [
                for (i = [0:N])
                let(x = -W / 2 + i * W / N)
                [x, y_top(x)]
            ],
            [
                [W / 2, y_bottom(W / 2)]
            ],
            [
                for (i = [N:-1:0])
                let(x = -W / 2 + i * W / N)
                [x, y_bottom(x)]
            ],
            [
                [-W / 2, y_top(-W / 2)]
            ]
        )
    );
}

module cover_outline_2d() {
    if (corner_r > 0) {
        offset(r = corner_r)
            offset(delta = -corner_r)
                cover_outline_raw_2d();
    } else {
        cover_outline_raw_2d();
    }
}

module top_plate() {
    linear_extrude(height = plate_thick)
        cover_outline_2d();
}

module holes() {
    translate([-30, 70, -20])
        cylinder(d = air_hole_d, h = 60);

    // translate([0, 70, -20]) cylinder(d = wire_hole_d, h = 60);

    translate([30, 70, -20])
        cylinder(d = air_hole_d, h = 60);
}

module engrave_revision_string() {
    translate([0, -D / 2 + 12, plate_thick - engrave_depth])
        linear_extrude(height = engrave_depth + 0.05)
            text(
                revision_string,
                size = engrave_size,
                font = "DejaVu Sans",
                halign = "center",
                valign = "center"
            );
}

module access_cover_flat() {
    difference() {
        top_plate();
        holes();
        engrave_revision_string();
    }
}

module handle() {
    h = 100;
    x = -h / 2;
    y = 0;
    d = 20;
    z = d / 2 + 3;

    translate([x, y, z])
        rotate([0, 90, 0])
            cylinder(d = d, h = h);
}

module assembly() {
    access_cover_flat();
    handle();
}

if (set == "plate") {
    access_cover_flat();
}

if (set == "" || set == "assembly") {
    assembly();
}

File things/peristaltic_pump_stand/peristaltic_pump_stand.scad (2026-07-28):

// Peristaltic pump stand: a horizontal motor plate and two end-panel legs.

set = "plate"; // [plate, legs, assembly]
revision_string = "dev";

// Measured pump dimensions and fit controls.
pump_count = 2;
pump_spacing = 62;
motor_hole_d = 29;
motor_screw_spacing = 48.5;
motor_clearance_h = 55;
mount_hole_d = 5.5;

// Print and construction dimensions.
render_fn = 64;
$fn = render_fn;
boolean_overlap = 0.1;
plate_t = 4;
plate_d = 44;
plate_end_margin = 12;
pump_mount_hole_d = 3.4;
leg_t = 4;
leg_tab_d = 10;
leg_slot_clearance = 0.25;
leg_print_gap = 10;
// Keep the M5 bore clear of the leg tab slot while the ear bridges around it.
// 33 mm outside diameter: twice the preceding 16.5 mm fit-test ear.
mount_ear_wall = 13.75;
leg_inset = 4;

plate_w = (pump_count - 1) * pump_spacing + motor_screw_spacing
    + 2 * plate_end_margin;
leg_x = plate_w / 2 - leg_t / 2 - leg_inset;
mount_ear_r = mount_hole_d / 2 + mount_ear_wall;
// Centre on the plate end: the exterior profile is a true semicircular ear.
mount_ear_x = plate_w / 2;

// Each station is collinear along X: M3, motor opening, M3.
module pump_station_negative(index) {
    x = (index - (pump_count - 1) / 2) * pump_spacing;
    translate([x, 0, -boolean_overlap]) {
        cylinder(d = motor_hole_d, h = plate_t + 2 * boolean_overlap);
        for (dx = [-motor_screw_spacing / 2, motor_screw_spacing / 2])
            translate([dx, 0, 0])
                cylinder(d = pump_mount_hole_d,
                    h = plate_t + 2 * boolean_overlap);
    }
}

module leg_slot_negative(x) {
    translate([
        x - (leg_t + leg_slot_clearance) / 2,
        -leg_tab_d / 2,
        -boolean_overlap
    ])
        cube([
            leg_t + leg_slot_clearance,
            leg_tab_d + leg_slot_clearance,
            plate_t + 2 * boolean_overlap
        ]);
}

module plate_positive() {
    union() {
        translate([-plate_w / 2, -plate_d / 2, 0])
            cube([plate_w, plate_d, plate_t]);

        // These ears place the table-mounting holes outside the end legs.
        for (x = [-mount_ear_x, mount_ear_x])
            translate([x, 0, 0])
                cylinder(d = 2 * mount_ear_r, h = plate_t);
    }
}

module plate() {
    difference() {
        plate_positive();

        for (index = [0:pump_count - 1]) pump_station_negative(index);

        for (x = [-mount_ear_x, mount_ear_x])
            translate([x, 0, -boolean_overlap])
                cylinder(d = mount_hole_d, h = plate_t + 2 * boolean_overlap);

        for (x = [-leg_x, leg_x]) leg_slot_negative(x);
    }
}

module leg_panel(height = motor_clearance_h) {
    union() {
        translate([-leg_t / 2, -plate_d / 2, 0])
            cube([leg_t, plate_d, height]);
        translate([-leg_t / 2, -leg_tab_d / 2, height])
            cube([leg_t, leg_tab_d, plate_t]);
    }
}

module leg_pair() {
    for (x = [-leg_x, leg_x])
        translate([x, 0, 0]) leg_panel(motor_clearance_h);
}

// Lay both panels flat on the bed, retaining their tab geometry.
module legs() {
    for (x = [0, motor_clearance_h + leg_print_gap])
        translate([x, 0, leg_t])
            rotate([0, 90, 0]) leg_panel(motor_clearance_h);
}

module assembly() {
    leg_pair();
    translate([0, 0, motor_clearance_h]) plate();
}

if (set == "plate") plate();
else if (set == "legs") legs();
else if (set == "assembly") assembly();

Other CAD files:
things/plamp_stand/prints/jul09_955c771/plamp_stand_plate_87566fc.stl
things/plamp8/plamp8.scad
tests/fixtures/cad_dependencies/root.scad
things/3d_template/scad/flat_plate.scad
things/3d_template/scad/positive_negative.scad
things/plamp_stand/plamp_stand.scad

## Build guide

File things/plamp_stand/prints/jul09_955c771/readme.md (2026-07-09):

# plamp_stand.scad
Thu Jul  9 11:12:52 AM HST 2026
source CAD:
```
git archive 87566fc947d268c4efcafbe8726270753ea43ae5 things/plamp_stand
```
## [plamp_stand_assembly_87566fc.stl](plamp_stand_assembly_87566fc.stl)

options: -D revision_string="87566fc" -D view="assembly" -D ball_quality=64

```
ECHO: ["view", "assembly"]
ECHO: "assmenbly view"
ECHO: "camera clip"
ECHO: "x", 34.65
ECHO: "y", 40.8
ECHO: "z", 0
ECHO: "dx", 1.25
ECHO: "dy", 20
ECHO: "dz", 10
Geometries in cache: 61
Geometry cache size in bytes: 1422864
CGAL Polyhedrons in cache: 17
CGAL cache size in bytes: 24365968
Total rendering time: 0:00:03.732
   Top level object is a 3D object:
   Simple:        yes
   Vertices:     3744
   Halfedges:   11232
   Edges:        5616
   Halffacets:   3786
   Facets:       1893
   Volumes:         4
```
## [plamp_stand_tripod_87566fc.stl](plamp_stand_tripod_87566fc.stl)

options: -D revision_string="87566fc" -D view="tripod" -D ball_quality=64

```
ECHO: ["view", "tripod"]
Geometries in cache: 9
Geometry cache size in bytes: 24408
CGAL Polyhedrons in cache: 2
CGAL cache size in bytes: 405152
Total rendering time: 0:00:00.204
   Top level object is a 3D object:
   Simple:        yes
   Vertices:      152
   Halfedges:     456
   Edges:         228
   Halffacets:    158
   Facets:         79
   Volumes:         2
```
## [plamp_stand_camera_clip_87566fc.stl](plamp_stand_camera_clip_87566fc.stl)

options: -D revision_string="87566fc" -D view="camera_clip" -D ball_quality=64

```
ECHO: ["view", "camera_clip"]
ECHO: "camera clip"
Geometries in cache: 10
Geometry cache size in bytes: 24560
CGAL Polyhedrons in cache: 1
CGAL cache size in bytes: 153808
Total rendering time: 0:00:00.154
   Top level object is a 3D object:
   Simple:        yes
   Vertices:      114
   Halfedges:     342
   Edges:         171
   Halffacets:    118
   Facets:         59
   Volumes:         2
```
## [plamp_stand_plate_87566fc.stl](plamp_stand_plate_87566fc.stl)

options: -D revision_string="87566fc" -D view="plate" -D ball_quality=64

```
ECHO: ["view", "plate"]
ECHO: "assmenbly view"
ECHO: "camera clip"
ECHO: "x", 34.65
ECHO: "y", 40.8
ECHO: "z", 0
ECHO: "dx", 1.25
ECHO: "dy", 20
ECHO: "dz", 10
Geometries in cache: 61
Geometry cache size in bytes: 1422864
CGAL Polyhedrons in cache: 17
CGAL cache size in bytes: 24365968
Total rendering time: 0:00:03.770
   Top level object is a 3D object:
   Simple:        yes
   Vertices:     3744
   Halfedges:   11232
   Edges:        5616
   Halffacets:   3786
   Facets:       1893
   Volumes:         4
```

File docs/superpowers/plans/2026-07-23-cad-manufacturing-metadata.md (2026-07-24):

# CAD Manufacturing Profiles and Slicing Metadata Implementation Plan

> **For agentic workers:** REQUIRED SUB-SKILL: Use superpowers:subagent-driven-development (recommended) or superpowers:executing-plans to implement this plan task-by-task. Steps use checkbox (`- [ ]`) syntax for tracking.

**Goal:** Add deterministic CAD-variable profiles, full value provenance, portable slicing requirements/recommendations, separate geometry/manufacturing fingerprints, and human README guidance.

**Architecture:** `cad_profiles` loads versioned system and instance-local profile overlays plus local defaults; `cad_manufacturing` normalizes and merges portable slicing directives with hard-conflict detection. `cad_planning` resolves profiles before structural product overrides, records every winning variable source, and emits both geometry and manufacturing identities for `cad_generation` to archive and explain.

**Tech Stack:** Python 3.11 standard library, frozen dataclasses, JSON, SHA-256, `argparse`, `unittest`

## Global Constraints

- This plan depends on completion of `2026-07-23-cad-system-catalog.md`.
- SCAD owns canonical variable definitions/defaults and Customizer constraints; external files only assign values.
- Low-to-high CAD precedence is SCAD source, model, set, ordered profiles, deepest product outward to selected top-level product, corresponding item at each layer, then CLI.
- Profile order is local defaults, top-level product, root-to-leaf product/items, model/set, then repeatable CLI profiles; later profiles win scalar profile conflicts.
- System and local profile IDs are separate (`system:name`, `local:name`); a short name is accepted only when unambiguous.
- `--no-default-profiles` disables instance defaults; every command prints selected profiles.
- Product/set hard manufacturing constraints cannot be weakened by profiles.
- Slicing metadata is portable advice in sidecars/manifests/READMEs; do not emit vendor profiles or 3MF.
- `required`/`forbidden` conflicts fail planning with both provenance paths.
- Slicing-only changes preserve geometry reuse but change the manufacturing fingerprint and README.
- Initial keys are orientation, supports, support style, ironing, material, layer height, perimeter/wall minimum, adhesion/brim, and ordered notes.

---

### Task 1: Load system and local profiles plus human defaults

**Files:**
- Create: `plamp/cad_profiles.py`
- Create: `tests/test_cad_profiles.py`
- Modify: `plamp/cad_system.py`
- Modify: `tests/test_cad_system.py`

**Interfaces:**
- Produces `CadProfileError`, `CadProfile`, `CadPreferences`,
  `load_system_profiles()`, `discover_local_profiles()`, `load_preferences()`,
  `resolve_profile_ids()`, and `profile_content_hash()`.
- Local profiles live at `$PLAMP_DATA_DIR/cad/profiles/*.json`; preferences live at `$PLAMP_DATA_DIR/cad/preferences.json`.
- `CadSystem.profiles` becomes `Mapping[str, CadProfile]` after loading.

- [ ] **Step 1: Write failing profile schema and resolution tests**

```python
def test_resolves_namespaces_defaults_and_explicit_profiles_in_order(self):
    system_profiles = {"draft": self.profile("draft", "quality")}
    local_profiles = {"x1c": self.profile("x1c", "printer", local=True)}
    result = resolve_profile_ids(
        system_profiles, local_profiles,
        defaults=("local:x1c",), requested=("system:draft",),
        use_defaults=True,
    )
    self.assertEqual(tuple(profile.qualified_id for profile in result),
                     ("local:x1c", "system:draft"))

def test_ambiguous_short_name_requires_qualified_id(self):
    with self.assertRaisesRegex(CadProfileError, "system:petg.*local:petg"):
        resolve_profile_ids(self.system_petg, self.local_petg,
                            defaults=(), requested=("petg",), use_defaults=True)
```

Cover strict keys/schema/kinds, finite typed CAD values, separate namespaces, stable hashes, absent preferences, malformed local files, default system/profile mappings, `--no-default-profiles`, and missing profile diagnostics.

- [ ] **Step 2: Run tests and verify RED**

Run: `.venv/bin/python -m unittest tests.test_cad_profiles -v`

Expected: FAIL because `plamp.cad_profiles` does not exist.

- [ ] **Step 3: Implement typed profile and preference loaders**

```python
@dataclass(frozen=True)
class CadProfile:
    name: str
    qualified_id: str
    kind: str
    path: Path
    cad: Mapping[str, object]
    slicing: Mapping[str, object]
    machine: Mapping[str, object]
    content_hash: str

@dataclass(frozen=True)
class CadPreferences:
    default_system: str | None = None
    default_profiles: Mapping[str, tuple[str, ...]] = field(default_factory=dict)
```

Use schemas `plamp-cad-profile/1` and `plamp-cad-preferences/1`. Profile kinds are exactly `printer`, `nozzle`, `material`, and `quality`. Hash canonical JSON bytes with sorted keys and compact separators. Preferences use:

```json
{
  "schema": "plamp-cad-preferences/1",
  "default_system": "plamp",
  "default_profiles": {"plamp": ["local:x1c", "system:petg"]}
}
```

Missing preference/local profile directories produce empty defaults; malformed present files produce CAD diagnostics rather than being ignored.

- [ ] **Step 4: Verify GREEN and commit**

Run:

```bash
.venv/bin/python -m unittest tests.test_cad_profiles tests.test_cad_system -v
python3 -m py_compile plamp/cad_profiles.py tests/test_cad_profiles.py
git diff --check
git add plamp/cad_profiles.py plamp/cad_system.py tests/test_cad_profiles.py tests/test_cad_system.py
git commit -m "Load CAD manufacturing profiles"
```

---

### Task 2: Parse SCAD defaults and resolve variable provenance

**Files:**
- Modify: `plamp/cad_model.py`
- Modify: `plamp/cad_values.py`
- Modify: `plamp/cad_planning.py`
- Modify: `tests/test_cad_model.py`
- Modify: `tests/test_cad_planning.py`

**Interfaces:**
- `CadModel.source_defaults` contains supported top-level literal Customizer assignments before the first module/function body.
- Produces `VariableLayer`, `ResolvedVariable`, and `resolve_variables()` and
  replaces Plan 1's winner-only `VariableSource` values.
- `RenderJob.variable_sources` records the ordered contributors and winner for every externally resolved variable.

- [ ] **Step 1: Write failing default parser and precedence tests**

```python
def test_parses_supported_customizer_literal_defaults(self):
    model = self.load_source('''
render_fn = 96; // [12:4:128]
render_text = true;
label = "normal";
offset = [1, 2, 3];
set = ""; // [floor]
module floor_set() { cube(1); }
''')
    self.assertEqual(model.source_defaults, {
        "render_fn": 96, "render_text": True,
        "label": "normal", "offset": [1, 2, 3], "set": "",
    })

def test_exact_precedence_and_provenance(self):
    job = self.plan_every_layer().jobs[0]
    self.assertEqual(job.variables["clearance"], 0.45)
    resolved = job.variable_sources["clearance"]
    self.assertEqual(tuple(layer.kind for layer in resolved.layers),
        ("scad", "model", "set", "profile", "product", "item", "cli"))
    self.assertEqual(resolved.winner.kind, "cli")
```

Cover booleans, strings, finite numbers, vectors, `undef`, unsupported expressions remaining source-owned/unresolved, typed values replacing lower raw values and vice versa, root-to-leaf profile order, deepest-to-outer product order, item locality, and CLI finality.

- [ ] **Step 2: Run tests and verify RED**

Run: `.venv/bin/python -m unittest tests.test_cad_model tests.test_cad_planning -v`

Expected: missing `source_defaults` and profile/provenance failures.

- [ ] **Step 3: Implement literal parsing and a single layer resolver**

```python
@dataclass(frozen=True)
class VariableLayer:
    kind: str
    source_id: str
    value: object | None = None
    raw_expression: str | None = None

@dataclass(frozen=True)
class ResolvedVariable:
    name: str
    layers: tuple[VariableLayer, ...]

    @property
    def winner(self) -> VariableLayer:
        return self.layers[-1]

def resolve_variables(layers: Sequence[tuple[str, str, Mapping[str, object], Mapping[str, str]]]):
    typed: dict[str, object] = {}
    raw: dict[str, str] = {}
    history: dict[str, list[VariableLayer]] = {}
    for kind, source_id, typed_values, raw_values in layers:
        for name, value in typed_values.items():
            typed[name] = value
            raw.pop(name, None)
            history.setdefault(name, []).append(
                VariableLayer(kind, source_id, value=value)
            )
        for name, expression in raw_values.items():
            raw[name] = expression
            typed.pop(name, None)
            history.setdefault(name, []).append(
                VariableLayer(kind, source_id, raw_expression=expression)
            )
    provenance = {
        name: ResolvedVariable(name, tuple(assignments))
        for name, assignments in history.items()
    }
    return typed, raw, provenance
```

Keep the history when typed/raw forms replace each other. Parse only literal
assignments with a small tokenizer; never evaluate Python or arbitrary SCAD
expressions. Exclude `set` from emitted overrides because the job selector owns
it.

- [ ] **Step 4: Verify GREEN and commit**

Run:

```bash
.venv/bin/python -m unittest tests.test_cad_model tests.test_cad_profiles tests.test_cad_planning -v
python3 -m py_compile plamp/cad_model.py plamp/cad_values.py plamp/cad_planning.py
git diff --check
git add plamp/cad_model.py plamp/cad_values.py plamp/cad_planning.py tests/test_cad_model.py tests/test_cad_planning.py
git commit -m "Resolve CAD variables with provenance"
```

---

### Task 3: Normalize and merge portable slicing directives

**Files:**
- Create: `plamp/cad_manufacturing.py`
- Create: `tests/test_cad_manufacturing.py`
- Modify: `plamp/cad_model.py`
- Modify: `plamp/cad_system.py`

**Interfaces:**
- Produces `ManufacturingConflict`, `DirectiveSource`, `SlicingDirective`,
  `ManufacturingPolicy`, `normalize_slicing()`, `merge_manufacturing()`, and
  `manufacturing_fingerprint()`.
- Plain `required`/`forbidden` recommendation values normalize as hard requirements; `recommended`/`discouraged`/`optional` normalize as preferences.
- Scalar directives default to preference strength unless represented as
  `{"value": "as-exported", "strength": "required"}` (or the corresponding
  typed scalar value).

- [ ] **Step 1: Write failing normalization/conflict tests**

```python
def test_profile_cannot_weaken_product_support_requirement(self):
    policy = merge_manufacturing((
        self.layer("product:box", {"supports": "required"}),
        self.layer("profile:draft", {"supports": "discouraged"}),
    ))
    self.assertEqual(policy.directives["supports"].value, "required")
    self.assertEqual(policy.directives["supports"].source.id, "product:box")

def test_conflicting_hard_requirements_report_both_sources(self):
    with self.assertRaises(ManufacturingConflict) as caught:
        merge_manufacturing((
            self.layer("set:top", {"supports": "forbidden"}),
            self.layer("product:complete", {"supports": "required"}),
        ))
    self.assertEqual(caught.exception.sources, ("set:top", "product:complete"))
```

Cover all portable keys, allowed vocabularies, explicit strength objects, ordered notes, later preference wins, hard-over-preference behavior, numeric layer height/perimeter validation, unknown keys, and stable manufacturing hashes.

- [ ] **Step 2: Run tests and verify RED**

Run: `.venv/bin/python -m unittest tests.test_cad_manufacturing -v`

Expected: FAIL because `plamp.cad_manufacturing` does not exist.

- [ ] **Step 3: Implement directive normalization and merging**

```python
@dataclass(frozen=True)
class SlicingDirective:
    key: str
    value: object
    strength: str  # "requirement" or "preference"
    source: DirectiveSource

@dataclass(frozen=True)
class ManufacturingPolicy:
    directives: Mapping[str, SlicingDirective]
    notes: tuple[tuple[str, str], ...]
    fingerprint: str
```

Normalize `supports` and `ironing` vocabularies, `orientation`, `support_style`, `material`, positive `layer_height`, positive integer `minimum_perimeters`, `adhesion`, and string-note arrays. During merge, two unequal requirements for one key raise `ManufacturingConflict`; a requirement always survives a preference; otherwise the later preference wins. Keep all notes in layer order with source IDs.

- [ ] **Step 4: Verify GREEN and commit**

Run:

```bash
.venv/bin/python -m unittest tests.test_cad_manufacturing tests.test_cad_model tests.test_cad_system -v
python3 -m py_compile plamp/cad_manufacturing.py
git diff --check
git add plamp/cad_manufacturing.py plamp/cad_model.py plamp/cad_system.py tests/test_cad_manufacturing.py
git commit -m "Merge portable CAD slicing guidance"
```

---

### Task 4: Integrate profiles and manufacturing policy into planning

**Files:**
- Modify: `plamp/cad_planning.py`
- Modify: `tests/test_cad_planning.py`
- Modify: `plamp/cad_cli.py`
- Modify: `tests/test_cad_cli.py`

**Interfaces:**
- `CadSelection` adds `profiles: tuple[str, ...]` and `use_default_profiles: bool`.
- `RenderJob` adds `profiles`, `manufacturing`, `geometry_fingerprint`, and
  `manufacturing_fingerprint`; remove the old `fingerprint` field and update all
  callers in this task.
- CLI adds repeatable `--profile` and `--no-default-profiles` to plan/generate/menu.

- [ ] **Step 1: Write failing integrated planning/CLI tests**

```python
def test_slicing_only_profile_preserves_geometry_fingerprint(self):
    plain = self.plan(profiles=()).jobs[0]
    ironing = self.plan(profiles=("system:ironing",)).jobs[0]
    self.assertEqual(plain.geometry_fingerprint, ironing.geometry_fingerprint)
    self.assertNotEqual(plain.manufacturing_fingerprint,
                        ironing.manufacturing_fingerprint)

def test_cli_prints_resolved_profiles_and_support_advice(self):
    output = self.run_text(["cad", "plan", "box", "--set", "top",
                            "--profile", "draft"])
    self.assertIn("Profiles: system:draft", output)
    self.assertIn("Supports: forbidden", output)
```

Cover default profile insertion/removal, product/item profile order, ambiguous short IDs, profile CAD values before products, hard conflicts as CAD2xx planning errors, JSON provenance, and fingerprint separation.

Also update `_selected_system()` to consult
`load_preferences(context.data_dir).default_system` after an explicit `--system`
and before one-system/interactive resolution. An invalid configured default must
name the preferences file and show the `plamp cad systems` choices.

- [ ] **Step 2: Run tests and verify RED**

Run: `.venv/bin/python -m unittest tests.test_cad_planning tests.test_cad_cli -v`

Expected: missing selection fields/options and fingerprint failures.

- [ ] **Step 3: Resolve the exact leaf-layer order**

For every expanded leaf, build profiles in this order:

```python
profile_ids = (
    default_profile_ids
    + selected_product_profiles
    + root_to_leaf_product_and_item_profiles
    + model_and_set_profile_ids
    + selection.profiles
)
```

Then apply variable layers as SCAD, model, set, ordered profiles, deepest product/item outward, CLI. Merge manufacturing in provenance order but mark product/set hard directives so later profile preferences cannot weaken them. Geometry hash includes selected profile hashes only when their `cad` namespace contributes an effective value; manufacturing hash includes every selected profile hash and resolved slicing policy.

- [ ] **Step 4: Add CLI options and verify GREEN**

Run:

```bash
.venv/bin/python -m unittest tests.test_cad_profiles tests.test_cad_manufacturing tests.test_cad_planning tests.test_cad_cli -v
python3 -m py_compile plamp/cad_planning.py plamp/cad_cli.py
git diff --check
git add plamp/cad_planning.py plamp/cad_cli.py tests/test_cad_planning.py tests/test_cad_cli.py
git commit -m "Apply profiles to CAD plans"
```

---

### Task 5: Archive provenance and render human manufacturing READMEs

**Files:**
- Modify: `plamp/cad_generation.py`
- Modify: `tests/test_cad_generation.py`
- Create: `plamp/cad_readme.py`
- Create: `tests/test_cad_readme.py`

**Interfaces:**
- `render_run_readme(manifest) -> str` is pure and deterministic.
- Job manifests record variable layers/winner, profile IDs/kinds/hashes, resolved manufacturing policy, geometry fingerprint, and manufacturing fingerprint.
- Duplicate geometry may be reused only when the archived artifact matches the geometry fingerprint; README/manifest are regenerated for changed manufacturing metadata.

- [ ] **Step 1: Write failing manifest/reuse/README tests**

```python
def test_readme_leads_with_artifacts_and_plain_slicing_guidance(self):
    text = render_run_readme(self.manifest(ironing="recommended",
                                           supports="forbidden"))
    self.assertIn("Enable ironing", text)
    self.assertIn("Do not generate supports", text)
    self.assertLess(text.index("Artifacts"), text.index("Variable provenance"))

def test_slicing_change_reuses_stl_but_rewrites_metadata(self):
    first = self.generate(profile="plain")
    second = self.generate(profile="ironing")
    self.assertEqual(self.openscad_calls, 1)
    self.assertNotEqual(first.manufacturing_fingerprint,
                        second.manufacturing_fingerprint)
```

Also cover orientation, support style, material, layer height, perimeter/adhesion advice, ordered notes, requirement wording, missing advice, full provenance JSON, and artifact checksum/help commands.

- [ ] **Step 2: Run tests and verify RED**

Run: `.venv/bin/python -m unittest tests.test_cad_readme tests.test_cad_generation -v`

Expected: missing renderer and old manifest schema failures.

- [ ] **Step 3: Implement pure README rendering and manifest fields**

```python
def render_run_readme(manifest: Mapping[str, object]) -> str:
    lines = [f"# CAD run {manifest['run_id']}", "", "## Artifacts", ""]
    lines.extend(("| Artifact | Model / set | Status |", "| --- | --- | --- |"))
    jobs = manifest.get("jobs", [])
    for job in jobs:
        lines.append(
            f"| {job['artifact_id']} | {job['model']} / "
            f"{job['set'] or '(default)'} | {job['status']} |"
        )
    for job in jobs:
        lines.extend(("", f"## {job['artifact_id']}", "", "Recommended slicing:", ""))
        directives = job.get("manufacturing", {}).get("directives", {})
        if directives.get("orientation", {}).get("value") == "as-exported":
            lines.append("- Use the exported orientation.")
        if directives.get("ironing", {}).get("value") == "recommended":
            lines.append("- Enable ironing.")
        if directives.get("supports", {}).get("value") == "forbidden":
            lines.append("- Do not generate supports.")
        for source_id, note in job.get("manufacturing", {}).get("notes", []):
            lines.append(f"- {note} ({source_id})")
    lines.extend((
        "", "## Inspection", "",
        "- Open `manifest.json` for profiles and variable provenance.",
        "- Open `logs/` for OpenSCAD output.",
        "- Open `source/` for the archived source.",
    ))
    return "\n".join(lines) + "\n"
```

Replace the inline `_write_readme()` composition with this pure renderer. Add a geometry-artifact lookup keyed by model/source identity plus `geometry_fingerprint`; hard-link or copy the prior STL into the new run while still creating fresh logs/manifest/README entries that state the reused run/artifact. Do not reuse failed or missing artifacts.

Include `manufacturing_fingerprint` in the complete run identity. A changed
slicing recommendation therefore creates a distinct run (and cannot trigger the
same-data regeneration prompt) while reusing the matching geometry artifact.

- [ ] **Step 4: Verify GREEN and commit**

Run:

```bash
.venv/bin/python -m unittest tests.test_cad_readme tests.test_cad_generation tests.test_cad_planning -v
python3 -m py_compile plamp/cad_readme.py plamp/cad_generation.py
git diff --check
git add plamp/cad_readme.py plamp/cad_generation.py tests/test_cad_readme.py tests/test_cad_generation.py
git commit -m "Archive CAD manufacturing guidance"
```

---

### Task 6: Add initial versioned profiles/guidance, document, and verify

**Files:**
- Create: `cad/profiles/draft.json`
- Modify: `cad/plamp.system.cad.json`
- Modify: `things/plamp8/plamp8.cad.json`
- Modify: `things/iharvest_cover/iharvest_cover.cad.json`
- Modify: `things/plamp_stand/plamp_stand.cad.json`
- Modify: `docs/host-tools.md`
- Modify: `tests/test_things_cad_scripts.py`
- Modify: `tests/test_cad_profiles.py`

**Interfaces:**
- `system:draft` sets only geometry quality (`render_fn`, `render_text`) and portable draft advice; it contains no guessed printer calibration.
- Existing printable sets receive verified orientation/support/ironing guidance; non-printable assembly sets remain `printable: false`.

- [ ] **Step 1: Write failing repository metadata tests**

```python
def test_plamp8_top_panel_recommends_ironing_without_supports(self):
    model = load_model("plamp8", PLAMP8_SIDECAR, REPO_ROOT)
    policy = normalize_slicing(model.sets["top_panel"].slicing,
                               source_id="set:plamp8/top_panel")
    self.assertEqual(policy["ironing"].value, "recommended")
    self.assertEqual(policy["supports"].value, "forbidden")
```

Add tests for draft profile schema, assembly non-printability, and docs covering profiles, local defaults, `--no-default-profiles`, and README advice.

- [ ] **Step 2: Add only known manufacturing guidance**

Use metadata already established by current print workflows. Do not invent printer dimensions, material shrinkage, support requirements, or layer heights. Put workstation-specific adjustments in documented local-profile examples under `$PLAMP_DATA_DIR`, not committed JSON.

- [ ] **Step 3: Run focused and full verification**

Run:

```bash
.venv/bin/python -m unittest tests.test_cad_profiles tests.test_cad_manufacturing tests.test_cad_planning tests.test_cad_readme tests.test_cad_generation tests.test_cad_cli tests.test_things_cad_scripts -v
.venv/bin/python -m unittest discover -s tests -v
python3 -m py_compile plamp/cad_*.py tests/test_cad_*.py
git diff --check
git status --short
```

Expected: all tests pass and only this slice's intended files are changed.

- [ ] **Step 4: Commit the completed manufacturing slice**

```bash
git add cad/profiles cad/plamp.system.cad.json things/*/*.cad.json docs/host-tools.md tests
git commit -m "Add CAD manufacturing profiles and guidance"
```

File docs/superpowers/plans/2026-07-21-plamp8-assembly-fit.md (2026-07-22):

# Plamp8 Assembly Fit Implementation Plan

> **For agentic workers:** REQUIRED SUB-SKILL: Use superpowers:subagent-driven-development (recommended) or superpowers:executing-plans to implement this plan task-by-task. Steps use checkbox (`- [ ]`) syntax for tracking.

**Goal:** Correct Plamp8 wall handedness, interior revision placement, panel-region clearance/support, and measured corner-nut fit while preserving the enclosure stack.

**Architecture:** Keep `things/plamp8/plamp8.scad` as the single parametric source and extend `tests/test_things_cad_scripts.py` with focused source contracts. Each geometry increment is test-first, committed, and pushed before the next increment; final validation uses the installed `plamp cad` dry-planning interface and does not render.

**Tech Stack:** OpenSCAD source, Python 3.11 `unittest`, Plamp CAD CLI, Git

## Global Constraints

- Keep the NORTH wall context matrix byte-for-byte unchanged; SOUTH, WEST, and EAST must be proper rotations with determinant `+1`.
- Preserve wall-local axes, box planes, shared wall bodies, and the existing assembly/fused-box call paths; do not add locator keys or wall copies.
- Keep floor thickness, holes, chamfers, locators, component supports, compass labels, and component labels unchanged.
- Keep `sub_panel_base_h = 5`, `sub_panel_h = 10`, top-panel thickness, wall height, corner supports, M3x20 panel screws, and M3x25/M3x30 corner screws unchanged.
- Do not change `side_loaded_panel_nut_trap()` or any `panel_nut_*` dimension.
- Do not commit generated STL, log, archive, manifest, or archived-source files.
- Do not invoke OpenSCAD before Task 1's source commit is pushed; this plan requires no OpenSCAD invocation at all.

---

### Task 1: Wall rotations, half-vent handedness, and interior floor revision

**Files:**
- Modify: `tests/test_things_cad_scripts.py`
- Modify: `things/plamp8/plamp8.scad`

**Failing tests:**
- `ThingsCadScriptsTest.test_plamp8_wall_contexts_are_proper_rotations`
- `ThingsCadScriptsTest.test_plamp8_half_vents_are_explicitly_handed`
- `ThingsCadScriptsTest.test_plamp8_floor_revision_is_readable_from_inside`

- [ ] **Step 1: Write the focused source-contract tests**

Parse the four `multmatrix()` literals and assert the exact matrices from the design, determinant `+1`, and an unchanged NORTH block. Assert `vent_side = "right"` flows through `flat_wall()`, `wall_vent_negatives()`, `wall_revision_negative()`, and `wall_stiffening_ribs()`; valid half sides are asserted; NORTH passes `"right"`; SOUTH passes `"left"`; and half-wall vent ranges, rib positions, and revision X use the selected side. Assert `box_bottom_revision_negative()` and its call are absent and `floor_revision_negative()` uses center `[box_w / 2, box_d / 2]`, interior Z `-box_h + wall_t`, depth `floor_revision_depth = 0.6`, angle zero, and no `mirror()`.

- [ ] **Step 2: Run RED**

Run:

```bash
.venv/bin/python -m unittest \
  tests.test_things_cad_scripts.ThingsCadScriptsTest.test_plamp8_wall_contexts_are_proper_rotations \
  tests.test_things_cad_scripts.ThingsCadScriptsTest.test_plamp8_half_vents_are_explicitly_handed \
  tests.test_things_cad_scripts.ThingsCadScriptsTest.test_plamp8_floor_revision_is_readable_from_inside -v
```

Expected: FAIL because SOUTH/WEST/EAST still contain reflected orientation blocks, half vents have no `vent_side`, and the floor revision is mirrored on the exterior face.

- [ ] **Step 3: Implement the minimum source change**

Replace only the SOUTH, WEST, and EAST context matrices with the approved matrices. Add asserted `vent_side` plumbing and derive left/right half vent ranges, mirrored rib X positions, and non-vented-half revision centers (`length / 4` or `3 * length / 4`); select right for NORTH and left for SOUTH. Replace the exterior revision cutter with `floor_revision_negative()` at the exact interior center/depth and call it from the existing floor negative composition.

- [ ] **Step 4: Run GREEN, commit, and push**

Run:

```bash
.venv/bin/python -m unittest tests.test_things_cad_scripts -v
git diff --check
git add tests/test_things_cad_scripts.py things/plamp8/plamp8.scad
git commit -m "Correct Plamp8 wall and floor orientation"
git push origin fix/plamp8-assembly-fit
```

Expected: all CAD source-contract tests pass, diff check is clean, and the source commit is on the remote before any optional render.

---

### Task 2: Panel layout, service grid, and separator ribs

**Files:**
- Modify: `tests/test_things_cad_scripts.py`
- Modify: `things/plamp8/plamp8.scad`

**Failing tests:**
- `ThingsCadScriptsTest.test_plamp8_panel_regions_have_two_mm_gaps_and_xt60_margin`
- `ThingsCadScriptsTest.test_plamp8_service_region_is_one_equal_cell_grid`
- `ThingsCadScriptsTest.test_plamp8_sub_panel_separator_ribs_follow_region_bounds`

- [ ] **Step 1: Write the focused source-contract tests**

Assert the exact constants and derived equations: `panel_region_gap = 2`, `dc_region_w = barrel_group_w = barrel_channel_w = 74`, `c13_group_w = service_group_w = 58`, `service_group_h = usb_c_group_h = 28`, unchanged `c13_cutout_w = 28`, and unchanged `c13_screw_spacing = 40`. Cover explicit SCAD assertions for 2 mm DC row/column/C13-service gaps, at least 1.2 mm XT60 X margin on every face, equal service cells, region-contained hardware/screw envelopes, and cutter-vs-rib bounds. Assert one `service_group_negative()`, a hardware-only `usb_c_connector_negative()`, and the 2x2 labels/connector centers (`plamp`, revision, `COM`, USB). Assert `sub_panel_separator_rib_positive(x0, y0, w, h)` and `sub_panel_separator_ribs_positive()` create exactly the two DC gap ribs and one C13/service gap rib from region bounds, from Z 5 through Z 10, while retaining the full-width USB rib.

- [ ] **Step 2: Run RED**

Run:

```bash
.venv/bin/python -m unittest \
  tests.test_things_cad_scripts.ThingsCadScriptsTest.test_plamp8_panel_regions_have_two_mm_gaps_and_xt60_margin \
  tests.test_things_cad_scripts.ThingsCadScriptsTest.test_plamp8_service_region_is_one_equal_cell_grid \
  tests.test_things_cad_scripts.ThingsCadScriptsTest.test_plamp8_sub_panel_separator_ribs_follow_region_bounds -v
```

Expected: FAIL on the current 70/66 mm regions, independently nudged USB region, nested USB pocket, and missing separator helpers.

- [ ] **Step 3: Implement the minimum source change**

Introduce the approved region constants and derive DC, C13, and service bounds from `panel_region_gap = 2`. Preserve the C13 cutout and screw locations. Split USB hardware cutting into `usb_c_connector_negative()` and the single service pocket; place the four equal service cells in the approved readable grid and keep the USB coupon by composing both cutters. Add only the vertical DC-column separator, horizontal DC-row separator, and horizontal C13/service separator at exactly 2 mm across-gap width and height `sub_panel_h - sub_panel_base_h`; union them with `sub_panel_8ch_positive()` without trimming around cutters. Add the exact layout, margin, envelope, and rib-side assertions required by the design.

- [ ] **Step 4: Run GREEN, commit, and push**

Run:

```bash
.venv/bin/python -m unittest tests.test_things_cad_scripts -v
git diff --check
git add tests/test_things_cad_scripts.py things/plamp8/plamp8.scad
git commit -m "Rework Plamp8 panel regions and supports"
git push origin fix/plamp8-assembly-fit
```

Expected: all CAD source-contract tests pass and the second source increment is pushed.

---

### Task 3: Measured corner-wall nut fit

**Files:**
- Modify: `tests/test_things_cad_scripts.py`
- Modify: `things/plamp8/plamp8.scad`

**Failing tests:**
- `ThingsCadScriptsTest.test_plamp8_corner_nut_fit_uses_measured_independent_dimensions`
- `ThingsCadScriptsTest.test_plamp8_corner_nut_fit_is_shared_by_flat_and_box_paths`

- [ ] **Step 1: Write the focused source-contract tests**

Assert `corner_nut_slot_l = 2.7`, `corner_nut_entry_w = 6.1`, `corner_nut_throat_w = 5.8`, `corner_nut_entry_detent = (corner_nut_entry_w - corner_nut_throat_w) / 2`, `corner_nut_entry_detent_l = 1.5`, and `corner_nut_pocket_d = corner_nut_entry_w / cos(30)`. Require assertions for all four measured values, 0.15 mm detent per side, and `entry - 2 * detent == throat`. Verify `support_free_m3_nut_trap()` uses these corner values in both flat point-up hex and box support-free paths, and does not use `panel_nut_entry_detent` or `panel_nut_entry_detent_l`. Retain existing M3x25 zero-offset and M3x30 enclosed-travel source contracts.

- [ ] **Step 2: Run RED**

Run:

```bash
.venv/bin/python -m unittest \
  tests.test_things_cad_scripts.ThingsCadScriptsTest.test_plamp8_corner_nut_fit_uses_measured_independent_dimensions \
  tests.test_things_cad_scripts.ThingsCadScriptsTest.test_plamp8_corner_nut_fit_is_shared_by_flat_and_box_paths -v
```

Expected: FAIL because the corner slot is derived from generic nut clearance and corner retention still depends on panel-detent controls.

- [ ] **Step 3: Implement the minimum source change**

Define the six approved corner-only dimensions and their exact assertions. Feed `corner_nut_entry_w`, `corner_nut_throat_w`, `corner_nut_entry_detent_l`, and `corner_nut_pocket_d` through the existing entry, detent, flat-pocket, and box-pocket modules. Preserve entry angle, screw axis/bore, nut bearing datum and offsets, tab/spine solids, coupon modules, and all panel-nut definitions.

- [ ] **Step 4: Run GREEN, commit, and push**

Run:

```bash
.venv/bin/python -m unittest tests.test_things_cad_scripts -v
git diff --check
git add tests/test_things_cad_scripts.py things/plamp8/plamp8.scad
git commit -m "Calibrate Plamp8 corner nut fit"
git push origin fix/plamp8-assembly-fit
```

Expected: all CAD source-contract tests pass and the third source increment is pushed.

---

### Task 4: Integrated CLI validation and review

**Files:**
- Modify only if review finds a missing cross-contract assertion: `tests/test_things_cad_scripts.py`
- Do not modify during this task: `things/plamp8/plamp8.scad`

**Failing tests / integration gates:**
- `tests.test_things_cad_scripts.ThingsCadScriptsTest` (all focused and legacy Plamp8 contracts)
- `tests.test_cad_cli.CadCliTests`
- `tests.test_cad_metadata.CadMetadataTests`
- `tests.test_cad_recipes.CadRecipeTests`

- [ ] **Step 1: Run the integration preflight**

Run:

```bash
.venv/bin/python -m unittest \
  tests.test_things_cad_scripts \
  tests.test_cad_cli \
  tests.test_cad_metadata \
  tests.test_cad_recipes -v
```

Expected: GREEN. Treat any failure as the integration RED signal: add one narrowly named source-contract assertion in `tests/test_things_cad_scripts.py` only when it exposes a missing approved-spec contract, then return the source correction to its owning Task 1, 2, or 3 commit instead of changing CAD here.

- [ ] **Step 2: Run non-rendering Plamp8 validation**

Run:

```bash
.venv/bin/plamp cad views plamp8 --json
.venv/bin/plamp cad validate plamp8 --json
.venv/bin/plamp cad plan plamp8 --preset split-box --json
.venv/bin/plamp cad plan plamp8 --preset fuse-box --json
```

Expected: each command exits 0 with valid JSON; `split-box` expands `floor`, `north_south_walls`, `east_west_walls`, `top_panel`, and `sub_panel`; `fuse-box` includes the fused `box` path plus the panel jobs declared by metadata. No command invokes OpenSCAD.

- [ ] **Step 3: Review invariants and repository cleanliness**

Confirm the NORTH matrix remained byte-identical, every context determinant is `+1`, no locator key or copied wall body appeared, panel and corner screw/stack values remain unchanged, panel-nut controls remain independent, and no generated artifact is tracked. Run:

```bash
git diff --check
git status --short
```

Expected: diff check is clean; status contains only an intentional final test-only review correction, or is clean.

- [ ] **Step 4: Commit any non-empty review correction and push the final checkpoint**

If Step 1 required a test-only correction, run:

```bash
git add tests/test_things_cad_scripts.py
git commit -m "Strengthen Plamp8 assembly fit contracts"
git push origin fix/plamp8-assembly-fit
```

Otherwise run only:

```bash
git push origin fix/plamp8-assembly-fit
```

Expected: the remote contains all three source increments and any genuine test-only integration correction; no empty commit is created.

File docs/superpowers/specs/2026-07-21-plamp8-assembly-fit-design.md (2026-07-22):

# Plamp8 Assembly Truth and Fit Corrections Design

**Date:** 2026-07-21

## Goal

Correct four observed Plamp8 print/assembly problems without changing the
enclosure stack:

- make every wall placement in `assembly` and fused `box` a physically
  realizable rotation rather than a reflection;
- put the floor revision where it can be read from inside the open box;
- give all four XT60 faces usable clearance while organizing and supporting
  the top/sub-panel service area; and
- make the corner-wall M3 nut catches accept the measured nuts without their
  current axial looseness.

The fixes remain parametric in `things/plamp8/plamp8.scad`. Source-contract
tests in `tests/test_things_cad_scripts.py` protect the dimensions,
handedness, and unchanged stack. Asymmetric floor locator keys remain a
deferred stretch goal.

## Wall coordinate and handedness contract

Wall-local coordinates remain authoritative: X runs along the wall, Y runs
along enclosure height/the corner-screw axis, and Z runs from the exterior
face toward the assembled box interior. A wall context transform is valid
only when the determinant of its 3x3 orientation block is `+1`. A determinant
of `-1` is a reflection and cannot describe placement of the printed part.

The existing NORTH transform is already correct and stays byte-for-byte
unchanged:

```scad
[
    [1, 0, 0, 0],
    [0, 0, -1, box_d],
    [0, 1, 0, -box_h],
    [0, 0, 0, 1]
]
```

SOUTH, WEST, and EAST use these proper rotations:

```scad
// SOUTH
[
    [-1, 0, 0, box_w],
    [0, 0, 1, 0],
    [0, 1, 0, -box_h],
    [0, 0, 0, 1]
]

// WEST
[
    [0, 0, 1, 0],
    [1, 0, 0, 0],
    [0, 1, 0, -box_h],
    [0, 0, 0, 1]
]

// EAST
[
    [0, 0, -1, box_w],
    [-1, 0, 0, box_d],
    [0, 1, 0, -box_h],
    [0, 0, 0, 1]
]
```

All four orientation blocks are orthogonal signed-permutation matrices with
determinant `+1`. The translations retain the same north/south/east/west box
planes. Consequently `NORTH`, `SOUTH`, `EAST`, `WEST`, and each wall revision
read normally in assembly; the CAD no longer obtains apparently correct hole
placement by mirroring text and geometry.

Half-wall ventilation becomes explicit instead of being hidden inside
`vent_mode = "half"`. Add `vent_side = "right"` to `flat_wall()`,
`wall_vent_negatives()`, `wall_revision_negative()`, and
`wall_stiffening_ribs()`. Valid half sides are `"left"` and `"right"` and are
asserted. `north_wall()` explicitly selects `"right"`; `south_wall()`
explicitly selects `"left"`. The left/right selection controls the vent-grid
range, the mirrored half-wall rib X positions, and revision placement. A
half-vented wall always engraves its revision at the center of the non-vented
half (`length / 4` or `3 * length / 4`), never over its holes. SOUTH therefore
has left-side vents in its printable source and the required left-side holes
when its readable physical wall is installed.

No asymmetric locator key, duplicate wall body, or view-dependent wall copy
is introduced. Both `assembly` and fused `box` continue to call these same
wall context modules.

## Interior floor revision

Delete `box_bottom_revision_negative()`. Replace it with
`floor_revision_negative()` centered at `[box_w / 2, box_d / 2]` on the
interior floor face `z = -box_h + wall_t`. It uses
`floor_revision_depth = 0.6`, no `mirror()`, and angle zero, so it reads while
looking into the open box from above. The cutter enters only from the interior
face. There is no revision geometry on the exterior/build-plate face.

The existing compass and component labels keep their positions and 0.6 mm
depths. Floor thickness, holes, chamfers, locators, and component supports do
not change.

## Top-panel region layout

Introduce one authoritative `panel_region_gap = 2` and derive all neighboring
rounded-region spacing from it. Replace local width assumptions with:

```scad
dc_region_w = 74;
barrel_group_w = dc_region_w;
barrel_channel_w = dc_region_w;
c13_group_w = 58;
service_group_w = c13_group_w;
service_group_h = usb_c_group_h;  // 28 mm
```

The existing layout equations continue to derive `dc_grid_x`,
`dc_col_spacing`, and `dc_row_spacing`; explicit assertions require both DC
column and row gaps to equal `panel_region_gap`. The width exchange from the
C13 region to the DC regions keeps the enclosure width unchanged: every DC
rounded pocket grows from 70 to 74 mm while the C13 rounded pocket shrinks
from 66 to 58 mm. The width-derived DC X centers become `-78` and `-2`, which
moves every XT60 face from protruding 0.75 mm beyond its pocket's left edge to
approximately 1.25 mm inside it. The DC row centers shift 2 mm from legacy
`75`/`27` to `73`/`25` so the real 32.5 mm switch envelopes clear the
continuous separator at y = 42..44.

`c13_cutout_w = 28`, `c13_screw_spacing = 40`, and the C13 hardware center
`(67, 58)` are invariant and covered by assertions. Narrowing moves only the
surrounding rounded rectangle center to x = 71; it does not move or resize the
C13 cutout or its screw holes.

The service region is one rounded rectangle directly below C13. Derive it
from shared region bounds, not independent nudges:

```scad
service_group_x = c13_region_x;
service_group_y = c13_hardware_y - c13_group_h / 2
    - panel_region_gap - service_group_h / 2;
service_cell_w = service_group_w / 2;
service_cell_h = service_group_h / 2;
```

Its four equal cells form this readable 2x2 grid:

```text
plamp       revision
COM         USB hole
```

Cell centers are derived as `service_group_x +/- service_cell_w / 2` and
`service_group_y +/- service_cell_h / 2`. `plamp` and `COM` occupy the left
column; the revision and USB connector occupy the right column. USB therefore
exits on the right for cable management. Split the existing USB negative into
a hardware-only `usb_c_connector_negative()` and the single
`service_group_negative()` rounded pocket so no second rounded rectangle is
hidden inside the service region. Both COM and USB belong to this one pocket.
The standalone USB fit coupon may compose those two modules to retain its
usefulness.

The service pocket follows the rounded C13 region rather than the offset C13
hardware center, retaining the 2 mm gap from the DC region. Its exact centers
are `(56.5, 17)` for plamp, `(85.5, 17)` for the revision, `(56.5, 3)` for COM,
and `(85.5, 3)` for USB.

Assertions protect the complete layout: every XT60 face is inside its DC
rounded bounds with at least 1.2 mm X margin; DC row/column gaps and the
C13/service gap are exactly 2 mm; the service cells share identical dimensions
and bounds; and C13/USB cutout and screw envelopes stay within their assigned
regions.

## Sub-panel separator supports

Keep the existing full-width USB support rib. Add only separator supports
whose centerlines and extents derive from the rounded-region bounds:

- one vertical support under the 2 mm gap between the two DC columns;
- one horizontal support under the 2 mm gap between the two DC rows; and
- one horizontal support under the 2 mm gap between C13 and the service
  region.

Use one helper,
`sub_panel_separator_rib_positive(x0, y0, w, h)`, and one composing module,
`sub_panel_separator_ribs_positive()`. Each rib starts at
`sub_panel_base_h`, rises exactly
`sub_panel_h - sub_panel_base_h`, and stops at the existing `sub_panel_h`
datum flush with the top-panel underside. Its across-gap width is exactly
`panel_region_gap`; its long extent spans the matching neighboring region
bounds. Intersections between separator ribs are intentional unions.

The support modules use layout coordinates consistently with
`sub_panel_8ch_positive()`; they do not contain corrective numeric offsets.
Bounding-box assertions require every DC, C13, USB, switch, screw, and XT60
nut-clearance cutter either to remain wholly on its assigned side of a rib or
to be an intentional opening through the pre-existing full-width USB rib.
Separator supports must not be silently trimmed around a cutter.

`sub_panel_base_h = 5`, `sub_panel_h = 10`, top-panel thickness, wall height,
corner supports, 20 mm panel screws, and 25/30 mm corner screws remain
unchanged.

## Corner-wall nut fit

This correction applies only to the top and bottom corner-wall nut catches
made by `support_free_m3_nut_trap()`. The top-panel
`side_loaded_panel_nut_trap()` and its `panel_nut_*` dimensions do not change.

Decouple the corner values from the panel-detent controls and define:

```scad
corner_nut_slot_l = 2.7;
corner_nut_entry_w = 6.1;
corner_nut_throat_w = 5.8;
corner_nut_entry_detent =
    (corner_nut_entry_w - corner_nut_throat_w) / 2;  // 0.15 mm/side
corner_nut_entry_detent_l = 1.5;
corner_nut_pocket_d = corner_nut_entry_w / cos(30);
```

The 2.7 mm axial slot replaces the current 3.1 mm slot around the measured
approximately 2.41 mm nut. The entry width is 6.1 mm, the retaining throat is
5.8 mm, and each positive detent is 0.15 mm. Assert all four values and the
identity `entry width - 2 * detent = throat width`.

Flat-wall and fused-box paths share these finished dimensions. The flat path
uses the point-up six-sided pocket with `corner_nut_pocket_d`, whose
flat-to-flat width is exactly 6.1 mm. The box path uses the same 6.1 mm core
and 2.7 mm axial length; only its global-print-up support-free roof differs.
Entry angle, screw axis, bore diameter, nut bearing-face datum, top and bottom
nut offsets, tab/spine solids, and coupon modules remain authoritative and
unchanged. The existing zero-offset M3x25 nut-face stack assertions and M3x30
enclosed-travel assertions must still pass.

## Verification and delivery

Implementation follows red-green-refactor in four reviewable increments:

1. wall rotations/vent handedness and the interior floor revision;
2. DC/C13/service layout and sub-panel separator supports;
3. corner-wall nut fit; and
4. integrated source-contract and `plamp cad` validation (no empty commit).

Before each source edit, add and run the focused failing source-contract test.
Use `plamp cad views plamp8 --json`, `plamp cad validate plamp8 --json`, and
`plamp cad plan plamp8 --preset split-box --json` plus `--preset fuse-box` for
non-rendering validation. Commit and push each small source increment for
early feedback. Do not invoke OpenSCAD until the first source commit is
pushed. Subsequent rendering is optional and only on user request; a successful
render is never evidence that printed hardware fits.

No generated STL, log, archive, or source snapshot is committed.

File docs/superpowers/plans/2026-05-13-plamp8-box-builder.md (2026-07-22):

# plamp8 Box Builder Implementation Plan

> **For agentic workers:** REQUIRED SUB-SKILL: Use superpowers:subagent-driven-development (recommended) or superpowers:executing-plans to implement this plan task-by-task. Steps use checkbox (`- [ ]`) syntax for tracking.

**Goal:** Evolve the existing OpenSCAD `plamp8` part with reusable channel modules, fit-test views, and a rough assembly/top-panel layout.

**Architecture:** Evolve the existing `things/plamp8` part through the direct `plamp cad` interface. Keep geometry correctness primarily human/print-verified; automated checks focus on CAD validation/planning and SCAD view/module structure. Use top-level parameters for all known and unknown hardware dimensions.

**Tech Stack:** OpenSCAD and the direct `plamp cad` CLI.

---

### Task 1: Evolve `plamp8`

**Files:**
- Modify: `things/plamp8/plamp8.scad`

- [ ] Replace the existing `plamp8.scad` with a modular SCAD file exposing `view = "assembly"; // [assembly, plate, ac_duplex_channel, dc_barrel_channel, usb_c_panel, c13_inlet, top_panel]`.
- [ ] Keep `revision_string = "dev"` and do not add generated STL files.

### Task 2: Implement reusable CAD modules

**Files:**
- Modify: `things/plamp8/plamp8.scad`

- [ ] Add top-level dimensions for plate thickness, outlet geometry, toggle holes, barrel jack holes, USB-C, C13, PSU keepout, relay keepout, relay mounting pattern, labels, and layout spacing.
- [ ] Add helper modules: rounded rectangles, rounded boxes, screw holes, label plaque/text, revision text, and alignment walls.
- [ ] Add channel modules: `ac_duplex_channel_unit(label_a, label_b, include_revision)`, `dc_barrel_channel_unit(label, include_revision)`, `usb_c_panel_unit(include_revision)`, `c13_inlet_unit(include_revision)`.
- [ ] Add internal context modules: `psu_keepout()` and `relay_board_keepout()` for assembly view only.

### Task 3: Implement views

**Files:**
- Modify: `things/plamp8/plamp8.scad`

- [ ] Add individual views for AC duplex, DC barrel, USB-C, C13, and top panel.
- [ ] Add `plate()` with separated printable coupons and the rough top panel laid out on the build plane.
- [ ] Add `assembly()` with rough box floor/walls, top panel, side/back C13 placement, and translucent/internal keepout placeholders.
- [ ] Ensure the full top panel has one revision string total; repeated modules must not duplicate revision strings in the full panel.

### Task 4: Lightweight verification

**Files:**
- Verify: `things/plamp8/plamp8.scad`

- [ ] Run `plamp cad validate plamp8 --json` and `plamp cad plan plamp8 --preset all-views --json`.
- [ ] Run `plamp cad generate plamp8 --preset all-views --revision plamp8-wip --output /tmp/plamp8_wip` only if OpenSCAD is available and time is reasonable. If rendering is slow, generate a single coupon with `plamp cad generate plamp8 --view VIEW --output DIR` or report that full rendering was skipped.
- [ ] Confirm no generated STL files were added to git.

### Task 5: Commit and push branch

**Files:**
- Add: `docs/superpowers/plans/2026-05-13-plamp8-box-builder.md`
- Modify: `things/plamp8/plamp8.scad`

- [ ] Commit with `git commit -m "Add plamp8 modular box builder"`.
- [ ] Push branch `plamp8-box-builder` to origin.

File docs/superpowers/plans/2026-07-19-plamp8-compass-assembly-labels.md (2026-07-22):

# Plamp8 Compass Assembly Labels Implementation Plan

> **For agentic workers:** REQUIRED SUB-SKILL: Use superpowers:subagent-driven-development (recommended) or superpowers:executing-plans to implement this plan task-by-task. Steps use checkbox (`- [ ]`) syntax for tracking.

**Goal:** Engrave matching full-word compass names into the interior faces of all four Plamp8 walls and their corresponding floor edges so wall placement is self-evident during assembly.

**Architecture:** Keep the existing single-file parametric OpenSCAD structure. Add one reusable wall-name negative and one reusable floor-name negative, pass each wall's identity explicitly at its standalone wall module, and reuse those modules in assembly context transforms. Source-contract tests lock down the names, dimensions, pairings, orientation, and positive/negative composition before OpenSCAD rendering verifies the printable geometry.

**Tech Stack:** OpenSCAD, Python 3.11 `unittest`, the direct `plamp cad` CLI, Git

## Global Constraints

- Use the full words `NORTH`, `SOUTH`, `EAST`, and `WEST`; do not substitute numbers or single letters.
- Use named `assembly_name_depth = 0.6` and `assembly_name_font = 7` parameters for both floor and wall engravings.
- Put all assembly names on printable interior faces; preserve the plain exterior build-plate faces.
- Do not replace or move any existing `revision_string` engraving.
- Wall names must remain below the first vent row and clear of the floor rib, stiffening ribs, vents, locator notches, corner hardware, and mating faces.
- Floor names must remain clear of component mounts, tie-wrap anchors, corner fasteners, locator lands, and wall seating faces.
- Orient floor names to read from the enclosure center while facing their matching wall: north `0°`, east `-90°`, south `180°`, west `90°` in the standard assembly top view.
- Render printable verification through `plamp cad generate`; keep generated STL and preview artifacts outside the repository.
- Commit and push after each task so geometry can receive early feedback.

---

### Task 1: Engrave compass names on all four walls

**Files:**
- Modify: `tests/test_things_cad_scripts.py`
- Modify: `things/plamp8/plamp8.scad`

**Interfaces:**
- Consumes: existing `write_text(string, font_size, z0)`, `flat_wall(...)`, four standalone wall modules, and four assembly context modules.
- Produces: `wall_assembly_name_negative(length, wall_name)`, the `wall_name` argument on `flat_wall`, and standalone wall modules that are the sole authority for each wall's compass identity.

- [ ] **Step 1: Add the failing wall-label source-contract test**

Add this method to `ThingsCadScriptsTest` in `tests/test_things_cad_scripts.py` immediately after `test_plamp8_has_four_flat_printed_mitred_wall_views`:

```python
    def test_plamp8_walls_have_full_compass_name_engravings(self):
        source = (REPO_ROOT / "things" / "plamp8" / "plamp8.scad").read_text()

        self.assertIn("assembly_name_depth = 0.6;", source)
        self.assertIn("assembly_name_font = 7;", source)
        self.assertIn("wall_assembly_name_y =", source)
        self.assertIn("module wall_assembly_name_negative", source)

        flat_wall = source.split("module flat_wall", 1)[1].split("module ", 1)[0]
        self.assertIn('wall_name = ""', flat_wall)
        self.assertIn("wall_assembly_name_negative(length, wall_name);", flat_wall)

        for wall in ("north", "south", "east", "west"):
            wall_module = source.split(f"module {wall}_wall()", 1)[1].split(
                "module ", 1
            )[0]
            self.assertIn(f'wall_name = "{wall.upper()}"', wall_module)

            context_module = source.split(
                f"module {wall}_wall_context()", 1
            )[1].split("module ", 1)[0]
            self.assertIn(f"{wall}_wall();", context_module)
```

- [ ] **Step 2: Run the focused test and confirm it fails**

Run:

```bash
.venv/bin/python -m unittest tests.test_things_cad_scripts.ThingsCadScriptsTest.test_plamp8_walls_have_full_compass_name_engravings -v
```

Expected: `FAIL`; the first missing contract is `assembly_name_depth = 0.6;`.

- [ ] **Step 3: Add shared engraving dimensions and the wall-name negative**

In `things/plamp8/plamp8.scad`, add these parameters beside the existing wall rib and vent dimensions:

```scad
assembly_name_depth = 0.6;
assembly_name_font = 7;
wall_assembly_name_y =
    (wall_t + wall_rib_w + vent_floor_clearance - vent_hole_d / 2) / 2;
```

Place this module immediately before `wall_revision_negative`:

```scad
module wall_assembly_name_negative(length, wall_name) {
    if (wall_name != "")
        translate([length / 2, wall_assembly_name_y, wall_t])
            write_text(wall_name, assembly_name_font, -assembly_name_depth);
}
```

Change `flat_wall` to accept and subtract the name:

```scad
module flat_wall(
    length,
    wall_name = "",
    nut_owner = false,
    vent_mode = "none",
    h = wall_z_height
) {
    difference() {
        union() {
            wall_body_positive(length, h);
            wall_corner_tabs(length, h, nut_owner);
            wall_stiffening_ribs(length, h, vent_mode);
        }
        floor_locator_notches(length);
        wall_vent_negatives(length, vent_mode, h);
        wall_revision_negative(length, h, vent_mode);
        wall_assembly_name_negative(length, wall_name);
    }
}
```

- [ ] **Step 4: Make standalone wall modules authoritative for identity**

Replace the four standalone wall bodies with:

```scad
module north_wall() {
    flat_wall(
        box_w,
        wall_name = "NORTH",
        nut_owner = true,
        vent_mode = "half"
    );
}

module south_wall() {
    flat_wall(
        box_w,
        wall_name = "SOUTH",
        nut_owner = true,
        vent_mode = "half"
    );
}

module west_wall() {
    flat_wall(
        box_d,
        wall_name = "WEST",
        nut_owner = false,
        vent_mode = "none"
    );
}

module east_wall() {
    flat_wall(
        box_d,
        wall_name = "EAST",
        nut_owner = false,
        vent_mode = "full"
    );
}
```

Inside each existing colored context transform, replace its direct `flat_wall(...)` call with the matching `north_wall();`, `south_wall();`, `west_wall();`, or `east_wall();` call. Preserve every color and transformation matrix exactly.

- [ ] **Step 5: Run focused and complete CAD source tests**

Run:

```bash
.venv/bin/python -m unittest tests.test_things_cad_scripts.ThingsCadScriptsTest.test_plamp8_walls_have_full_compass_name_engravings -v
.venv/bin/python -m unittest tests.test_things_cad_scripts -v
git diff --check
```

Expected: the focused test passes, all `tests.test_things_cad_scripts` tests pass, and `git diff --check` produces no output.

- [ ] **Step 6: Render all four labeled walls**

Run from `things/plamp8` with a fresh temporary parent:

```bash
label_preview_root="$(mktemp -d)"
plamp cad generate plamp8 --revision compass-walls-1 --view north_wall --output "$label_preview_root/north"
plamp cad generate plamp8 --revision compass-walls-1 --view south_wall --output "$label_preview_root/south"
plamp cad generate plamp8 --revision compass-walls-1 --view east_wall --output "$label_preview_root/east"
plamp cad generate plamp8 --revision compass-walls-1 --view west_wall --output "$label_preview_root/west"
test -s "$label_preview_root/north/plamp8_north_wall_compass-walls-1.stl"
test -s "$label_preview_root/south/plamp8_south_wall_compass-walls-1.stl"
test -s "$label_preview_root/east/plamp8_east_wall_compass-walls-1.stl"
test -s "$label_preview_root/west/plamp8_west_wall_compass-walls-1.stl"
! rg -n "WARNING|ERROR|empty top level object" "$label_preview_root"/*/readme.md
```

Expected: four non-empty STL files and no warning, error, or empty-object matches. Inspect each interior face and confirm the complete word is recessed, centered, below the first vent row, and separated from the lower horizontal rib.

- [ ] **Step 7: Commit and push the wall checkpoint**

```bash
git add tests/test_things_cad_scripts.py things/plamp8/plamp8.scad
git commit -m "Engrave compass names on Plamp8 walls"
git push origin feature/plamp8-flat-walls
```

Expected: one new commit appears on `feature/plamp8-flat-walls` and the push succeeds.

---

### Task 2: Engrave matching names on the floor and verify the assembly

**Files:**
- Modify: `tests/test_things_cad_scripts.py`
- Modify: `things/plamp8/plamp8.scad`

**Interfaces:**
- Consumes: Task 1's `assembly_name_depth`, `assembly_name_font`, and existing floor `difference()` composition.
- Produces: `floor_assembly_name_inset`, `floor_assembly_name_negative(label, x, y, angle)`, and `floor_assembly_name_negatives()` with one correctly oriented entry for every wall.

- [ ] **Step 1: Add the failing floor-label source-contract test**

Add this method immediately after the wall-label test:

```python
    def test_plamp8_floor_has_matching_oriented_compass_names(self):
        source = (REPO_ROOT / "things" / "plamp8" / "plamp8.scad").read_text()

        self.assertIn("floor_assembly_name_inset = 14;", source)
        self.assertIn("module floor_assembly_name_negative", source)
        self.assertIn("module floor_assembly_name_negatives", source)

        floor_names = source.split(
            "module floor_assembly_name_negatives", 1
        )[1].split("module ", 1)[0]
        expected = (
            '("NORTH", box_w / 2, box_d - wall_t - floor_assembly_name_inset, 0)',
            '("EAST", box_w - wall_t - floor_assembly_name_inset, box_d / 2, -90)',
            '("SOUTH", box_w / 2, wall_t + floor_assembly_name_inset, 180)',
            '("WEST", wall_t + floor_assembly_name_inset, box_d / 2, 90)',
        )
        for call in expected:
            self.assertIn(f"floor_assembly_name_negative{call};", floor_names)

        floor_context = source.split("module floor_context()", 1)[1].split(
            "module ", 1
        )[0]
        self.assertIn("floor_assembly_name_negatives();", floor_context)
```

- [ ] **Step 2: Run the focused test and confirm it fails**

Run:

```bash
.venv/bin/python -m unittest tests.test_things_cad_scripts.ThingsCadScriptsTest.test_plamp8_floor_has_matching_oriented_compass_names -v
```

Expected: `FAIL`; `floor_assembly_name_inset = 14;` is absent.

- [ ] **Step 3: Add the four parametric floor engravings**

Add this parameter beside the assembly-name dimensions:

```scad
floor_assembly_name_inset = 14;
```

Place these modules immediately before `floor_context`:

```scad
module floor_assembly_name_negative(label, x, y, angle) {
    translate([x, y, -box_h + wall_t])
        rotate([0, 0, angle])
            write_text(label, assembly_name_font, -assembly_name_depth);
}

module floor_assembly_name_negatives() {
    floor_assembly_name_negative("NORTH", box_w / 2, box_d - wall_t - floor_assembly_name_inset, 0);
    floor_assembly_name_negative("EAST", box_w - wall_t - floor_assembly_name_inset, box_d / 2, -90);
    floor_assembly_name_negative("SOUTH", box_w / 2, wall_t + floor_assembly_name_inset, 180);
    floor_assembly_name_negative("WEST", wall_t + floor_assembly_name_inset, box_d / 2, 90);
}
```

In the negative section of `floor_context`, add the floor assembly names after the existing revision negative:

```scad
            floor_corner_fastener_holes();
            box_bottom_revision_negative();
            floor_assembly_name_negatives();
```

- [ ] **Step 4: Run focused and complete CAD source tests**

Run:

```bash
.venv/bin/python -m unittest tests.test_things_cad_scripts.ThingsCadScriptsTest.test_plamp8_floor_has_matching_oriented_compass_names -v
.venv/bin/python -m unittest tests.test_things_cad_scripts -v
git diff --check
```

Expected: the focused test passes, all CAD script tests pass, and `git diff --check` produces no output.

- [ ] **Step 5: Render the floor and complete assembly with text enabled**

Run from `things/plamp8`:

```bash
label_preview_root="$(mktemp -d)"
plamp cad generate plamp8 --revision compass-floor-1 --view floor --output "$label_preview_root/floor"
plamp cad generate plamp8 --revision compass-floor-1 --view assembly --output "$label_preview_root/assembly"
test -s "$label_preview_root/floor/plamp8_floor_compass-floor-1.stl"
test -s "$label_preview_root/assembly/plamp8_assembly_compass-floor-1.stl"
! rg -n "WARNING|ERROR|empty top level object" "$label_preview_root"/*/readme.md
```

Expected: both STL files are non-empty and logs contain no warning, error, or empty-object matches. Inspect the floor interior to confirm all four words are readable from the center while facing their matching walls, remain inside the floor skin, and do not intersect mounts, anchors, locators, fasteners, or wall seats. Inspect the assembly to confirm the floor-to-wall pairings are correct.

- [ ] **Step 6: Run final verification**

```bash
.venv/bin/python -m unittest tests.test_things_cad_scripts -v
git diff --check
git status --short
```

Expected: all CAD script tests pass, the diff check is silent, and only `tests/test_things_cad_scripts.py` plus `things/plamp8/plamp8.scad` are modified.

- [ ] **Step 7: Commit and push the completed compass-label feature**

```bash
git add tests/test_things_cad_scripts.py things/plamp8/plamp8.scad
git commit -m "Pair Plamp8 walls with floor labels"
git push origin feature/plamp8-flat-walls
```

Expected: the second implementation commit appears on `feature/plamp8-flat-walls` and the push succeeds.

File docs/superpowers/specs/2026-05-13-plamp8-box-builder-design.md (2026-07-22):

# plamp8 Modular Box Builder Design

## Goal

Create a modular OpenSCAD CAD builder for the `plamp8` relay enclosure. The first implementation should produce useful fit-test prints and establish reusable CAD modules for the final enclosure, without trying to finish the entire box in one pass.

The current `things/plamp8` double-wall outlet plate is the starting point. The builder should evolve this part in place, preserving its outlet cutout approach and inscription style while adding modular channels and views.

## CAD Part

Use the existing part directory:

```text
things/plamp8/
  plamp8.scad
```

Use the existing part metadata conventions and the direct `plamp cad` interface. Create future parts with `plamp cad new PART [--template NAME]`.

The SCAD file must expose ordered views:

```scad
view = "assembly"; // [assembly, plate, ac_duplex_channel, dc_barrel_channel, usb_c_panel, c13_inlet, top_panel]
```

The generator will export views in this order, so keep the most useful visualization first and fit-test parts after.

## Product Model

The box controls eight relay channels:

- Four 120V outlet channels, physically represented as two duplex outlet channel units.
- Four 12V channels, physically represented as four barrel-jack channel units.
- One USB-C panel connector for service/control access.
- One C13 mains input with switch for 120V input, likely on a side/back wall rather than the top.
- Internal space for a 12V/5V PSU, 8-channel relay board, and diode wiring. These internals are represented as keepout placeholders in the first pass. The relay board can show known mounting hole positions, but detailed standoffs are not part of the first pass.

All connectors should be on the top panel except the 120V input, which may move to a side/back wall.

## CAD Architecture

Model reusable channel units as CAD modules, not separate final inserts.

The first pass creates a single printable top-panel concept plus separate fit-test coupons for each module. The final enclosure can later reuse the same modules in a full box body.

Core modules:

- `ac_duplex_channel_unit(label_a, label_b)`: One double-wall outlet plate area with two outlet cutouts, two toggle holes, labels, and underside alignment walls/ribs.
- `dc_barrel_channel_unit(label)`: One 2.1 mm barrel jack cutout, one toggle hole, label, and underside alignment walls/ribs.
- `usb_c_panel_unit()`: USB-C panel connector cutout using the measured 14 mm by 8 mm rectangle and two M3 screw holes 20 mm apart.
- `c13_inlet_unit()`: C13 inlet and switch cutout using the measured 1.9 inch by 2.0 inch opening, with tunable screw holes. This may be placed on a side wall in the final assembly.
- `psu_keepout()`: Internal 12V/5V PSU keepout using the measured 160 mm by 98 mm by 38 mm envelope. Do not add screw mounts until hole positions are measured.
- `relay_board_keepout()`: Internal Waveshare Pico relay keepout using the measured 145 mm by 90 mm by 40 mm envelope. Show four 5 mm mounting hole positions on a 135 mm by 70 mm XY pattern for layout planning.
- `top_panel_8ch()`: Places two AC duplex channel units and four DC barrel channel units on one top panel.
- `assembly()`: Shows the rough full box/top layout assembled in place.
- `plate()`: Lays out all printable/testable pieces separated for export.

## Dimensions And Parameters

Known values:

- Toggle switch mounting hole: `toggle_hole_d = 12`.
- Duplex outlet mounting has one visible center screw hole plus two screws under the face plate. These should be treated as available load paths for outlet retention where practical.
- 2.1 mm barrel jack mounting hole: `barrel_jack_hole_d = 12`.
- USB-C panel connector cutout: `usb_c_cutout_w = 14`, `usb_c_cutout_h = 8`.
- USB-C panel connector screws: two M3 screws, `usb_c_screw_spacing = 20`, centered around the rectangular cutout.
- C13 mains inlet/switch module cutout: `c13_cutout_w = 1.9 * 25.4`, `c13_cutout_h = 2.0 * 25.4`.
- C13 screw holes: left and right, vertically centered on the inlet; screw diameter and exact spacing remain tunable. Initial spacing should be derived from the 1.9 inch width minus 1-2 mm inset per side.
- PSU keepout: `psu_w = 160`, `psu_d = 98`, `psu_h = 38`.
- Waveshare Pico relay keepout: `relay_w = 145`, `relay_d = 90`, `relay_h = 40`.
- Waveshare Pico relay mounting holes: `relay_mount_hole_d = 5`, `relay_mount_x = 135`, `relay_mount_y = 70`.
- Final top/channel plate thickness: `plate_t = 3`.
- The existing `plamp8` outlet plate geometry is a useful starting reference.

Unknown values should be explicit parameters with conservative defaults:

- Toggle switch body keepout rectangle width/depth.
- 2.1 mm barrel jack nut/body keepout.
- C13 inlet screw diameter and exact screw spacing.
- PSU screw mount positions.
- Final enclosure width/depth/height and wall thickness.
- Internal keepout sizes for wire paths and diode wiring.

Do not hide unknown hardware dimensions in magic numbers. Name them so they can be tuned after caliper measurements or fit-test prints.

## Views

`assembly`:

Show the rough assembled top panel and early enclosure context. This can be visually approximate in the first pass. It should make placement and spacing understandable.

`plate`:

Lay out all printable fit-test pieces separated on the build plane. This should include at least the AC duplex channel coupon, DC barrel channel coupon, USB-C panel coupon, C13 inlet coupon, and rough top panel if printable at current size.

Individual fit-test views:

- `ac_duplex_channel`: Render only the AC duplex channel test piece.
- `dc_barrel_channel`: Render only the DC barrel channel test piece.
- `usb_c_panel`: Render only the USB-C panel connector test piece.
- `c13_inlet`: Render only the C13 inlet/switch test piece.
- `top_panel`: Render only the rough top panel.

## Mechanical Intent

Underside alignment walls/ribs should be part of each channel module. They are not separate inserts; they are reusable CAD geometry that helps locate hardware and stiffen the panel.

AC outlet channels must resist both downward and upward forces from plugging and unplugging cords. The outlet should not rely only on thin panel material around the cutout. The CAD should provide local stiffness and retention around the duplex channel, using the center screw and the two screws hidden under the face plate as mounting/load-transfer points where practical.

The first pass should prefer printable, easy-to-measure coupons over a highly detailed final enclosure. Each coupon should make one hardware fit question answerable.

Labels should be parameterized and readable. Revision branding should use `revision_string` so generated STLs can be tied to the commit hash or explicit dirty revision text.

Channel labels should be two lines: a large device name on the first line and a smaller channel/Pico-pin line on the second line. The strings should be top-level parameters so relay channel numbers and Pico pins can be assigned later. Default AC outlet device names are `Pump`, `Lights`, `Fan`, and `Aux`. Default DC barrel channel device names are `PH up`, `PH down`, `Agitator`, and `Nutrients`.

Revision branding is per printable part, not per repeated module. The full top panel should have one revision string total even if it contains two duplex channel modules and four DC channel modules. The eventual box body should also have one revision string. Individual fit-test coupons may include their own revision string because each coupon is a standalone printable part.

Label construction should follow the successful `plamp8` approach: text is extruded from a rounded rectangle that sits lower than the top surface, leaving the text flush with the panel surface rather than raised above it.

## Non-Goals For First Pass

- No detailed relay-board standoffs or fastener design, beyond showing the known mounting hole pattern for layout planning.
- No detailed PSU mount.
- No screw bosses for the final box unless they fall out naturally from the top-panel prototype.
- No separate removable cartridge inserts.
- No automatic layout solver. Placement is parametric but manually defined.
- No assumption that unknown connector dimensions are final.

## Testing And Verification

Use the CAD generator rather than direct OpenSCAD calls:

```bash
plamp cad generate plamp8 --preset all-views --revision fit-test-1 --output /tmp/plamp8_fit
```

Expected verification:

- `plamp cad validate plamp8 --json`
- `plamp cad plan plamp8 --preset all-views --json`
- Render all declared views through `plamp cad generate`.
- Confirm STL files are created and non-empty.
- Treat OpenSCAD non-manifold warnings as informational for early fit-test coupons unless the geometry is visibly empty or broken.

## Open Questions For Implementation

- Exact 2.1 mm barrel jack nut/body keepout behind the known 12 mm panel hole.
- Exact toggle switch rectangular body keepout size under the 12 mm mounting hole.
- C13 inlet screw diameter and exact screw spacing.
- Exact duplex outlet hidden faceplate screw positions and screw diameter.
- PSU screw mount positions.
- Final enclosure footprint and whether the C13 inlet goes on the back or side.

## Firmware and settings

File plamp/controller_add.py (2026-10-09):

"""Pure Plamp8 controller-profile conversion helpers."""

import json
import re
from dataclasses import asdict, dataclass
from collections.abc import Callable
from pathlib import Path
from typing import Any

from plamp.config import (
    ConfigError,
    atomic_write_json,
    load_config,
    save_config,
    validate_config,
)
from plamp.locks import exclusive_lock
from plamp.pico_commands import upgrade_scheduler
from plamp.pico_firmware import firmware_revision
from plamp.pico_transport import request_report
from plamp.scheduler_state import (
    EXPECTED_FIRMWARE_PROTOCOL,
    FirmwareIdentity,
    firmware_identity,
    normalize_scheduler_state,
)


@dataclass(frozen=True)
class ProfileChannel:
    pin: int
    device_id: str
    mode: str


PLAMP8_CHANNELS = (
    ProfileChannel(21, "ph_up", "ready"),
    ProfileChannel(20, "ph_down", "ready"),
    ProfileChannel(19, "agitator", "ready"),
    ProfileChannel(18, "nutrients", "ready"),
    ProfileChannel(17, "pump", "scheduled"),
    ProfileChannel(16, "fan", "scheduled"),
    ProfileChannel(15, "lights_1", "scheduled"),
    ProfileChannel(14, "lights_2", "scheduled"),
)

_SAFE_PATH_COMPONENT_RE = re.compile(r"^[A-Za-z0-9_-]+$")


def display_device_id(device_id: str) -> str:
    text = device_id.replace("_", " ")
    return text[:1].upper() + text[1:]


def _report_devices(report: Any) -> list[dict[str, Any]]:
    if not isinstance(report, dict) or report.get("type") != "report":
        raise ValueError("controller response must be a report")
    content = report.get("content") if isinstance(report, dict) else None
    devices = content.get("devices") if isinstance(content, dict) else None
    if not isinstance(devices, list):
        raise ValueError("report must contain devices")
    if not all(isinstance(device, dict) for device in devices):
        raise ValueError("report devices must be objects")
    return devices


def _supported_identity(report: Any) -> FirmwareIdentity:
    identity = firmware_identity(report)
    if identity is None:
        raise ValueError("report must contain a firmware identity")
    if identity.name != "pico_scheduler":
        raise ValueError("report firmware must be pico_scheduler")
    if not identity.revision:
        raise ValueError("report firmware revision must be a non-empty string")
    if identity.protocol not in {2, EXPECTED_FIRMWARE_PROTOCOL}:
        raise ValueError(f"unsupported firmware protocol: {identity.protocol}")
    return identity


def _report_integer(
    value: Any, label: str, *, maximum: int | None = None
) -> int:
    if isinstance(value, bool) or not isinstance(value, int) or value < 0:
        raise ValueError(f"{label} must be an integer >= 0")
    if maximum is not None and value > maximum:
        raise ValueError(f"{label} must be <= {maximum}")
    return value


def _profile_report_devices(
    report: Any,
) -> tuple[list[dict[str, Any]], dict[int, dict[str, Any]], FirmwareIdentity]:
    identity = _supported_identity(report)
    devices = _report_devices(report)
    if len(devices) not in {0, len(PLAMP8_CHANNELS)}:
        raise ValueError("report must contain exactly eight profile devices")
    devices_by_pin: dict[int, dict[str, Any]] = {}
    for device in devices:
        pin = device.get("pin")
        if not isinstance(pin, int) or isinstance(pin, bool):
            raise ValueError("report devices must use integer pins")
        if pin in devices_by_pin:
            raise ValueError("report must contain unique profile pins")
        devices_by_pin[pin] = device
    profile_pins = {channel.pin for channel in PLAMP8_CHANNELS}
    if devices and set(devices_by_pin) != profile_pins:
        raise ValueError("report must contain exactly the Plamp8 profile pins")
    return devices, devices_by_pin, identity


def _validated_report_state(
    report: Any,
) -> tuple[dict[str, Any], dict[int, dict[str, Any]], FirmwareIdentity]:
    report_devices, devices_by_pin, identity = _profile_report_devices(report)
    required = {
        "id",
        "type",
        "pin",
        "elapsed_t",
        "current_value",
        "reschedule",
        "pattern",
    }
    if identity.protocol == EXPECTED_FIRMWARE_PROTOCOL:
        required.add("mode")
    state_devices = []
    for index, source in enumerate(report_devices):
        if not required <= set(source):
            raise ValueError(f"device {index} has invalid fields")
        _report_integer(source["elapsed_t"], f"device {index} elapsed_t")
        cycle_t = _report_integer(
            source.get("cycle_t", source["elapsed_t"]),
            f"device {index} cycle_t",
        )
        current_value = _report_integer(
            source["current_value"], f"device {index} current_value", maximum=1
        )
        mode = source.get("mode")
        if mode is None and isinstance(source.get("enabled"), bool):
            mode = "scheduled" if source["enabled"] else "ready"
        if mode == "ready" and current_value != 0:
            raise ValueError(f"device {index} ready current_value must be integer 0")
        state_devices.append(
            {
                "id": source.get("id"),
                "type": source.get("type"),
                "pin": source.get("pin"),
                "mode": (
                    mode
                    if identity.protocol == EXPECTED_FIRMWARE_PROTOCOL
                    else "scheduled"
                ),
                "current_t": cycle_t,
                "reschedule": source.get("reschedule"),
                "pattern": source.get("pattern"),
            }
        )
    return normalize_scheduler_state({"devices": state_devices}), devices_by_pin, identity


def _matches_plamp8_profile(state: dict[str, Any]) -> bool:
    devices_by_pin = {device["pin"]: device for device in state["devices"]}
    if set(devices_by_pin) != {channel.pin for channel in PLAMP8_CHANNELS}:
        return False
    return all(
        devices_by_pin[channel.pin]["id"] == channel.device_id
        and devices_by_pin[channel.pin]["type"] == "gpio"
        and devices_by_pin[channel.pin]["mode"] == channel.mode
        for channel in PLAMP8_CHANNELS
    )


def _is_importable(
    identity: FirmwareIdentity,
    expected_identity: FirmwareIdentity,
    state: dict[str, Any],
) -> bool:
    return identity == expected_identity and _matches_plamp8_profile(state)
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

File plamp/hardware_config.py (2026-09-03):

"""Validation helpers for the persisted hardware config."""

from __future__ import annotations

from collections.abc import Mapping
from pathlib import PurePosixPath
import re


_ID_RE = re.compile(r"^[A-Za-z0-9_-]+$")
_SCHEDULE_KINDS = {"cycle", "daily_window", "events"}
_PIN_TYPES = {"gpio"}
_CONTROLLER_TYPES = {"pico_scheduler"}
_DEVICE_TYPES = {"scheduled_output"}
_DEFAULT_CONTROLLER_TYPE = "pico_scheduler"
_DEFAULT_REPORT_EVERY = 10
_CONFIG_KEYS = ("controllers", "cameras")
_RESERVED_CONTROLLER_IDS = {"controllers", "config", "pics", "pico_scheduler"}
_AUTOFOCUS_MODES = {"auto", "continuous", "manual", "off"}
_PROGRAMMING_MODES = {"scheduled", "ready"}
_LEGACY_PROGRAMMING = {"enabled": "scheduled", "disabled": "ready"}


def empty_config() -> dict:
    return {key: {} for key in _CONFIG_KEYS}


def normalize_programming(value: object, label: str, *, default: str = "scheduled") -> str:
    if value is None:
        value = default
    if value in _LEGACY_PROGRAMMING:
        value = _LEGACY_PROGRAMMING[value]
    if value not in _PROGRAMMING_MODES:
        raise ValueError(f"{label} programming must be scheduled or ready")
    return value


def _is_valid_id(value: object) -> bool:
    return isinstance(value, str) and bool(_ID_RE.fullmatch(value))


def _as_mapping(value: object, label: str) -> Mapping:
    if not isinstance(value, Mapping):
        raise ValueError(f"{label} must be a mapping")
    return value


def _optional_label(item: Mapping, label: str) -> str | None:
    value = item.get("label")
    if value in (None, ""):
        return None
    if not isinstance(value, str):
        raise ValueError(f"{label} label must be a string")
    return value


def _required_positive_int(value: object, label: str) -> int:
    if not isinstance(value, int) or isinstance(value, bool):
        raise ValueError(f"{label} must be a positive integer")
    if value <= 0:
        raise ValueError(f"{label} must be a positive integer")
    return value


def _required_non_negative_int(value: object, label: str) -> int:
    if not isinstance(value, int) or isinstance(value, bool):
        raise ValueError(f"{label} must be a non-negative integer")
    if value < 0:
        raise ValueError(f"{label} must be a non-negative integer")
    return value


def _required_bool(value: object, label: str) -> bool:
    if not isinstance(value, bool):
        raise ValueError(f"{label} must be a boolean")
    return value


def _optional_repo_relative_path(value: object, label: str) -> str | None:
    if value in (None, ""):
        return None
    if not isinstance(value, str):
        raise ValueError(f"{label} must be a string")
    if "\\" in value:
        raise ValueError(f"{label} must be repo-relative")
    path = PurePosixPath(value)
    if path.is_absolute() or path == PurePosixPath(".") or ".." in path.parts:
        raise ValueError(f"{label} must be repo-relative")
    return value


def _optional_name_token(value: object, label: str) -> str | None:
    if value in (None, ""):
        return None
    if not _is_valid_id(value):
        raise ValueError(f"{label} must be a valid id")
    return str(value)


def validate_controllers(value):
    value = _as_mapping(value, "controllers")
    controllers = {}
    for controller_id, controller_value in value.items():
        if not _is_valid_id(controller_id):
            raise ValueError(f"invalid controller id: {controller_id!r}")
        if controller_id in _RESERVED_CONTROLLER_IDS:
            raise ValueError(f"controller id is reserved: {controller_id!r}")
        controller_value = _as_mapping(controller_value, f"controller {controller_id}")
        extra_keys = set(controller_value) - {"type", "payload", "config", "settings", "devices"}
        if extra_keys:
            raise ValueError(f"controller {controller_id} has unknown keys: {sorted(extra_keys)!r}")

        controller_type = controller_value.get("type", _DEFAULT_CONTROLLER_TYPE)
        if controller_type not in _CONTROLLER_TYPES:
            raise ValueError(f"controller {controller_id} type must be one of {sorted(_CONTROLLER_TYPES)!r}")

        payload = _as_mapping(controller_value.get("payload", {}), f"controller {controller_id} payload")
        config = _as_mapping(controller_value.get("config", {}), f"controller {controller_id} config")
        settings = _as_mapping(controller_value.get("settings", {}), f"controller {controller_id} settings")
        extra_config = set(config) - {"pico_serial", "label"}
        if extra_config:
            raise ValueError(f"controller {controller_id} config has unknown keys: {sorted(extra_config)!r}")
        extra_settings = set(settings) - {"report_every", "devices", "label"}
        if extra_settings:
            raise ValueError(f"controller {controller_id} settings has unknown keys: {sorted(extra_settings)!r}")
        pico_serial = payload.get("pico_serial", config.get("pico_serial"))
        if pico_serial is not None and (not isinstance(pico_serial, str) or not pico_serial):
            raise ValueError(f"controller {controller_id} pico_serial must be a non-empty string")
        legacy_label = _optional_label(config, f"controller {controller_id}")
        settings_label = _optional_label(settings, f"controller {controller_id}")
        if "devices" in settings:
            semantic_devices = _validate_semantic_devices(settings["devices"], controller_id)
            legacy_devices = None
        else:
            legacy_devices = validate_controller_devices(
                controller_value.get("devices", {}),
                controller_id,
                "pico_scheduler",
            )
            semantic_devices = _semantic_devices_from_legacy(legacy_devices)
        controller = {
            "type": controller_type,
            "payload": {
                "report_every": _required_positive_int(
                    payload.get("report_every", settings.get("report_every", _DEFAULT_REPORT_EVERY)),
                    f"controller {controller_id} report_every",
                ),
                "devices": _scheduler_payload_devices(payload.get("devices"), semantic_devices, legacy_devices, controller_id),
            },
            "settings": {"devices": semantic_devices},
        }
        label = settings_label or legacy_label
        if label:
            controller["settings"]["label"] = label
        if pico_serial is not None:
            controller["payload"]["pico_serial"] = pico_serial
        controllers[controller_id] = controller
    return controllers
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

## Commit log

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2026-03-24 Print Pico scheduler state validation errors
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2026-03-25 Use content field for Pico scheduler errors
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2026-03-25 Return False directly from Pico scheduler errors
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2026-04-03 docs: tighten grow loop operating model
2026-04-06 added hook for ph/ec/temp meter
    [plamp_stand.scad]
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2026-04-14 fixing problems the config page (and running out of tokens)
    [pages.py, server.py]
2026-04-15 Replace persisted hardware config model
    [hardware_config.py]
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2026-04-15 Fix live pin detail in plan doc
2026-04-15 Fix timer schedule editor refresh behavior
    [pages.py, server.py, timer_schedule.py]
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2026-04-15 Fix settings controller renames
    [pages.py, server.py, timer_schedule.py]
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2026-04-15 Show settings validation errors
    [pages.py]
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2026-04-17 Fix GitHub issue reports
    [hardware_config.py, pages.py, timer_schedule.py]
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2026-04-22 Fix service PATH and refresh git status
    [server.py]
2026-04-23 Fix grow capture discovery in worktrees
    [camera_capture.py]
2026-05-01 Add pico schedulers settings redesign spec
2026-05-01 Tighten peripheral assignment rendering
    [pages.py]
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2026-05-01 Tighten grouped scheduler layout
    [pages.py]
2026-05-01 Fix hidden scheduler preservation encoding
    [pages.py]
2026-05-01 Fix scheduler controller save edge cases
    [pages.py]
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2026-05-01 Fix pico scheduler device table layout
    [pages.py]
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2026-05-04 Fix timer dashboard devices parsing
    [pages.py]
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2026-05-04 Tighten pico scheduler live device snapshots
    [server.py]
2026-05-04 Fix pico scheduler device snapshot writes
    [server.py]
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2026-05-08 Fix camera capture script defaults and simplify camera settings table
    [camera_capture.py, pages.py, server.py]
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2026-05-08 Fix settings JS nullish-coalescing parse error
    [pages.py]
2026-05-08 Improve missing-image capture error details without fallback
    [camera_capture.py]
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2026-05-09 Fix mobile dashboard button text
    [pages.py]
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2026-05-09 Make plampctl upgrade skip current branch
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2026-05-13 Add iharvest_cover OpenSCAD part
    [iharvest_cover.scad]
2026-05-14 Improve OpenSCAD CAD tooling
    [flat_plate.scad, positive_negative.scad]
2026-05-14 Add plamp8 relay cover CAD
    [plamp8.scad]
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2026-05-14 Add plamp8 modular box builder
    [plamp8_box.scad]
2026-05-14 Move modular builder into plamp8
    [plamp8.scad, plamp8_box.scad]
2026-05-14 Restore plamp8 as modular builder base
    [plamp8.scad]
2026-05-14 Make plamp8 modular labels flush
    [plamp8.scad]
2026-05-14 Group plamp8 channel pockets
    [plamp8.scad]
2026-05-14 Parameterize plamp8 channel labels
    [plamp8.scad]
2026-05-14 Rework plamp8 top panel service layout
    [plamp8.scad]
2026-05-14 Refine plamp8 panel spacing
    [plamp8.scad]
2026-05-14 Label plamp8 relay pins
    [plamp8.scad]
2026-05-14 Offset plamp8 outlet plate for toggles
    [plamp8.scad]
2026-05-14 Improve plamp8 panel cutouts and spacing
    [plamp8.scad]
2026-05-14 Refine plamp8 connector and dc layout
    [plamp8.scad]
2026-05-14 Tighten plamp8 panel layout
    [plamp8.scad]
2026-05-14 Repack plamp8 top panel layout
    [plamp8.scad]
2026-05-15 Adjust plamp8 service stack layout
    [plamp8.scad]
2026-05-15 Tighten plamp8 left side layout
    [plamp8.scad]
2026-05-15 Fit plamp8 top panel under 250mm
    [plamp8.scad]
2026-05-15 Align plamp8 top panel blocks
    [plamp8.scad]
2026-05-15 Equalize plamp8 dc channel gaps
    [plamp8.scad]
2026-05-15 Align plamp8 service gap
    [plamp8.scad]
2026-05-15 Trim plamp8 panel to content margins
    [plamp8.scad]
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2026-05-15 Refine plamp8 labels and inlet cutout
    [plamp8.scad]
2026-05-15 Add plamp8 internal layout view
    [plamp8.scad]
2026-05-15 Repack plamp8 internal keepouts
    [plamp8.scad]
2026-05-15 Rotate plamp8 internal keepouts
    [plamp8.scad]
2026-05-15 Place plamp8 PSU along vented side
    [plamp8.scad]
2026-05-16 Stand plamp8 PSU on side
    [plamp8.scad]
2026-05-16 Center plamp8 relay keepout
    [plamp8.scad]
2026-05-16 Return plamp8 PSU to flat layout
    [plamp8.scad]
2026-05-16 Add plamp8 lid ledge and clearance
    [plamp8.scad]
2026-05-16 Simplify plamp8 lid ledge
    [plamp8.scad]
2026-05-16 Use four plamp8 lid lips
    [plamp8.scad]
2026-05-16 Hide plamp8 panel outline by default
    [plamp8.scad]
2026-05-16 Seat plamp8 lid flush in assembly
    [plamp8.scad]
2026-05-16 Size plamp8 cavity to lid
    [plamp8.scad]
2026-05-16 Add plamp8 corner lid screws
    [plamp8.scad]
2026-05-16 Hide plamp8 internal context by default
    [plamp8.scad]
2026-05-16 Add plamp8 relay mount holes
    [plamp8.scad]
2026-05-16 Adjust plamp8 outlet and lip fit
    [plamp8.scad]
2026-05-16 Add plamp8 nut traps and PSU tie points
    [cad.scad, flat_plate.scad, plamp8.scad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]
2026-05-16 Revise plamp8 PSU strap anchors
    [plamp8.scad]
2026-05-16 Make plamp8 PSU anchors printable arches
    [plamp8.scad]
2026-05-16 Refine plamp8 lid bosses and wall anchors
    [plamp8.scad]
2026-05-16 Move plamp8 lid screws toward corners
    [plamp8.scad]
2026-05-16 Remove plamp8 corner bosses
    [plamp8.scad]
2026-05-16 Raise plamp8 box and wall anchors
    [plamp8.scad]
2026-05-16 Add plamp8 PSU locator stops
    [plamp8.scad]
2026-05-16 Vent plamp8 PSU-side walls
    [plamp8.scad]
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2026-05-17 moved internal_clearance_h definition and added feature_psu_tie_wrap_anchors
    [plamp8.scad]
2026-05-17 Seat plamp8 PSU against right wall
    [plamp8.scad]
2026-05-17 Lengthen plamp8 PSU stops between anchors
    [plamp8.scad]
2026-05-17 Move plamp8 floor anchors outside PSU
    [plamp8.scad]
2026-05-17 Increase plamp8 PSU anchor clearance
    [plamp8.scad]
2026-05-17 Engrave plamp8 box revision
    [plamp8.scad]
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2026-05-20 Fix schedule editor reopen and cycle units
    [pages.py]
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2026-05-20 Fix timer reapply after schedule config save
    [pages.py]
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2026-05-20 Fix inline schedule editor cancel button
    [pages.py]
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2026-05-21 Tighten filtered status snapshots
    [server.py]
2026-05-21 Fix filtered status path routing
    [pages.py, server.py]
2026-05-21 Tighten system storage labels
    [pages.py]
2026-05-21 Fix API test status stream start
    [pages.py]
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2026-05-22 Add plamp8 sub panel
    [plamp8.scad]
2026-05-22 Fix plamp8 sub panel cutouts
    [plamp8.scad]
2026-05-22 Adjust plamp8 sub panel USB opening
    [plamp8.scad]
2026-05-22 Raise plamp8 sub panel socket mounts
    [plamp8.scad]
2026-05-22 Lower plamp8 box ledge for sub panel
    [plamp8.scad]
2026-05-22 Mirror plamp8 box bottom revision engraving
    [plamp8.scad]
2026-05-22 Add voltage labels to plamp8 panel
    [plamp8.scad]
2026-05-23 crude patch to avoid ph up and ph down toggles to interfere with 1/4 cylinder box ledge
    [plamp8.scad]
2026-05-24 moved top panel in internal view
    [plamp8.scad]
2026-05-24 Refine plamp8 assembly view controls
    [plamp8.scad]
2026-05-24 Add XT60 option for plamp8 DC connectors
    [plamp8.scad]
2026-05-24 Use XT60 connector cutout on plamp8 panels
    [plamp8.scad]
2026-05-24 Adjust plamp8 12V recess pockets
    [plamp8.scad]
2026-05-24 Stretch plamp8 revision recess
    [plamp8.scad]
2026-05-24 Tighten plamp8 AC recess spacing
    [plamp8.scad]
2026-05-24 Even plamp8 AC and DC recess gaps
    [plamp8.scad]
2026-05-24 Adjust plamp8 sub panel switch height
    [plamp8.scad]
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2026-07-03 Fix plamp8 PSU holes and corner overlap
    [plamp8.scad]
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2026-07-03 Offset plamp8 PSU holes from short edges
    [plamp8.scad]
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2026-07-03 Flip plamp8 ledge profile
    [plamp8.scad]
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2026-07-06 Fix dashboard serial log JavaScript newline
    [pages.py]
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2026-07-09 Add converter retaining clearance
    [plamp8.scad]
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2026-07-12 Tighten plamp8 AC socket fit
    [plamp8.scad]
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2026-07-14 Document plamp8 XT60 switch clearance
2026-07-14 Plan plamp8 XT60 switch clearance
2026-07-14 Increase plamp8 XT60 switch clearance
    [plamp8.scad]
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2026-07-15 Revert "Require fresh report after Pico apply"
    This reverts commit dfafd06496b1c2d0e3d2e5473e0c4264dbc1889c.
    [server.py]
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2026-07-15 Fix Pico report framing and deadlines
    [pico_transport.py]
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2026-07-15 Correct Plamp8 USB COM mount fit
    [plamp8.scad]
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2026-07-16 Flatten USB fit panel and support nut trap roof
    [plamp8.scad]
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2026-07-16 Preserve Pico configure recovery errors
    [pico_transport.py]
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2026-07-19 Require interference-free Plamp8 assembly
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2026-07-19 Fix Plamp8 corner coupon and split ledge ring
    [plamp8.scad]
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2026-07-19 Remove interfering Plamp8 floor lands
    [plamp8.scad]
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2026-07-19 Strengthen Plamp8 corner tab stack
    [plamp8.scad]
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2026-07-20 Loosen Plamp8 component fit
    [plamp8.scad]
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2026-07-21 Resolve CAD generation recipes
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2026-07-22 Plan named CAD scaffold review fixes
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2026-07-22 Resolve relative OpenSCAD paths safely
    [cad_generation.py]
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2026-07-22 Document Plamp8 assembly fit corrections
2026-07-22 Plan Plamp8 assembly fit corrections
2026-07-22 Correct Plamp8 wall and floor orientation
    [plamp8.scad]
2026-07-22 Tighten half-vent propagation contracts
2026-07-22 Rework Plamp8 panel regions and supports
    [plamp8.scad]
2026-07-22 Fix Plamp8 service coupon and rib bounds
    [plamp8.scad]
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2026-07-22 Use measured width for box corner nut pocket
    [plamp8.scad]
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2026-07-22 Fix Plamp8 OpenSCAD definition order
    [plamp8.scad]
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2026-07-24 Resolve CAD variables with provenance
    [cad_model.py, cad_planning.py, cad_values.py]
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2026-07-24 Make CAD reuse publication no-replace
    [cad_generation.py]
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2026-07-24 Reject CAD archive prefix collisions
    [cad_dependencies.py]
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2026-07-25 Correct panel nut roof orientation
    [plamp8.scad]
2026-07-25 Orient flipped panel nut test geometry
    [plamp8.scad]
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2026-07-26 Fix seated nut catcher retention geometry
    [plamp8.scad]
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2026-07-26 Fix Plamp8 wall ribs and corner nut catchers
    [plamp8.scad]
2026-07-26 Correct Plamp8 corner nut catcher entry
    [plamp8.scad]
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2026-07-27 Plan nut catcher jig orientation fix
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2026-07-27 Correct PSU and converter floor fit
    [plamp8.scad]
2026-07-27 Fix nut catcher jig roof coupons
    [plamp8.scad]
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2026-07-27 Shorten nut jig adjustment labels
    [plamp8.scad]
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2026-07-27 Correct sideways catcher roof angle
    [plamp8.scad]
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2026-07-28 Expand compact nut catcher matrix to seven by seven
    [plamp8.scad]
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2026-07-28 Move nut catcher scale grid to matrix top
    [plamp8.scad]
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2026-07-28 Trim matrix back wall and round flat roof bore
    [plamp8.scad]
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2026-08-04 Raise plamp8 walls and clarify controller errors
    [plamp8.scad]
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2026-08-06 Fix Plamp8 top wall boss overlap
    [plamp8.scad]
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2026-08-06 Shorten Plamp8 east west top bosses
    [plamp8.scad]
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2026-08-10 Correct 45 degree nut coupon design
2026-08-10 Fix Plamp8 diagonal nut coupon tunnel
    [plamp8.scad]
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2026-08-10 Fix sideways Plamp8 nut insertion path
    [plamp8.scad]
2026-08-10 Fix enlarged nut coupon engravings
    [plamp8.scad]
2026-08-10 Correct pointy nut catcher design
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2026-08-15 Fix controller provisioning blockers
    [controller_add.py, hardware_config.py, pages.py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]
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2026-08-23 Model Plamp8 auto-only service clearances
    [plamp8.scad]
2026-08-23 Fix auto-only CAD verification commands
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2026-09-01 Fix scheduler state truth and clock resync
    [timer_schedule.py]
2026-09-02 Quiet routine picamera2 log noise.
    Keep camera success chatter out of plamp.log and emit clear warnings only when capture or start fails.
    [camera_capture.py, server.py]
2026-09-02 Log plamp-web revision on startup.
    Make service restarts visible in plamp.log with the deployed short git revision.
    [server.py]
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2026-09-03 Rename schedule modes to scheduled/ready end-to-end (protocol 4).
    Replace enabled/disabled with mode scheduled|ready from firmware through config and dashboard, add pulse-history traces for ready channels, and keep Pulse ON/OFF without schedule toggle.
    [controller_add.py, hardware_config.py, pages.py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]
2026-09-03 Polish ready-channel dashboard: history labels, short-pulse traces, stream warn.
    Rename history axes to last hour / last 24h / last 30 days, keep short pulses visible via window sampling, and turn the OK status yellow between 5–10s of stream silence before error.
2026-09-15 Keep Plamp8 power standoffs printable and enlarge sub-panel nuts.
    Floor mount tubes were collapsing into the M5 countersink; the cone now stays in the floor and the tubes match its head diameter. Sub-panel XT60/C13 towers and bores are roomier, with fastener labels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
    [plamp8.scad]
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2026-10-09 Make the camera ribbon fill the panel and move by click or wheel.
    The phone-sized frame caps left the pictures too small to aim at with a mouse.
    [camera_ribbon.py]
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2026-10-09 Give the finder fixed scale labels, an hour summary, and a Now button.
    The summary shows the full date and how far the hour is from the start and from today, and Now keeps the latest picture selected.
    [camera_ribbon.py, server.py]
2026-10-09 Give the finder fixed hour, day, and growing week sliders.
    Hours always cover 24 stops and days always cover Monday through Sunday, with blank frames where a picture is missing. Weeks run from the first week through this week.
    [camera_ribbon.py, server.py]
2026-10-09 Keep latest selected and show every picture on the hour slider.
    A day with extra shots still includes an empty stop for each missing hour, and an open finder refreshes when a new capture arrives.
    [camera_ribbon.py, server.py]
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2026-10-10 Remove the camera ribbon now that the finder is the other view.
    The tab, page, and ribbon-only API were a comparison UI the finder replaced.
    [camera_ribbon.py, server.py]
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
